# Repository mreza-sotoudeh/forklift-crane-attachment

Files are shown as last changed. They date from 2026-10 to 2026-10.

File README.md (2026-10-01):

# Forklift Crane Attachment

Design and analysis of an adjustable crane attachment for a forklift, including structural calculations, mechanical joints, manufacturing drawings, and a complete SolidWorks assembly.

## Authors

* Ali Sakhaei
* Mohammadreza Sotoudeh

## Project Overview

This academic machine-design project develops a removable crane attachment for a 3-ton forklift. The mechanism provides adjustable reach and boom angle while remaining fully demountable and manually adjustable.

The project covers forklift stability, static loading, structural members, bolts, pins, welds, component selection, CAD modeling, engineering drawings, and assembly documentation.

## Design Requirements

| Requirement | Value |
| --- | ---: |
| Forklift capacity | 3 tonnes |
| Fork length | 1000 mm |
| Fork cross-section | 120 × 40 mm |
| Fork spacing | 800 mm center-to-center |
| Maximum hook reach beyond fork tips | 2500 mm |
| Boom angles | 0°, 15°, 30°, and 45° |
| Hook-position increments | 200 mm |
| Required forklift stability factor of safety | 1.5 |
| Adjustment method | Manual |
| Installation | Fully removable |

## Key Design Features

* Telescopic boom for adjustable lifting reach
* Multiple predefined boom-angle positions
* Hook locations arranged at 200 mm intervals
* Removable connection to the forklift forks
* Bolted, pinned, and welded mechanical joints
* Structural calculations for the main load-carrying components
* Complete SolidWorks parts, assemblies, and engineering drawings

## Design and Analysis

The design process included:

* Forklift stability evaluation at different boom configurations
* Static load analysis of the boom and supporting structure
* Selection and verification of bolts and clevis pins
* Weld sizing and connection assessment
* Evaluation of rectangular hollow sections, plates, channels, and angles
* Preparation of a bill of materials and manufacturing drawings
* Assembly modeling and interference checking in SolidWorks

## CAD Model

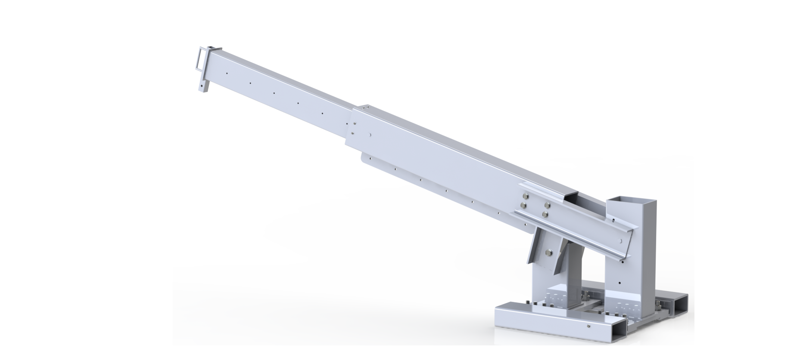
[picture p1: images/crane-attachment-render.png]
Crane attachment render


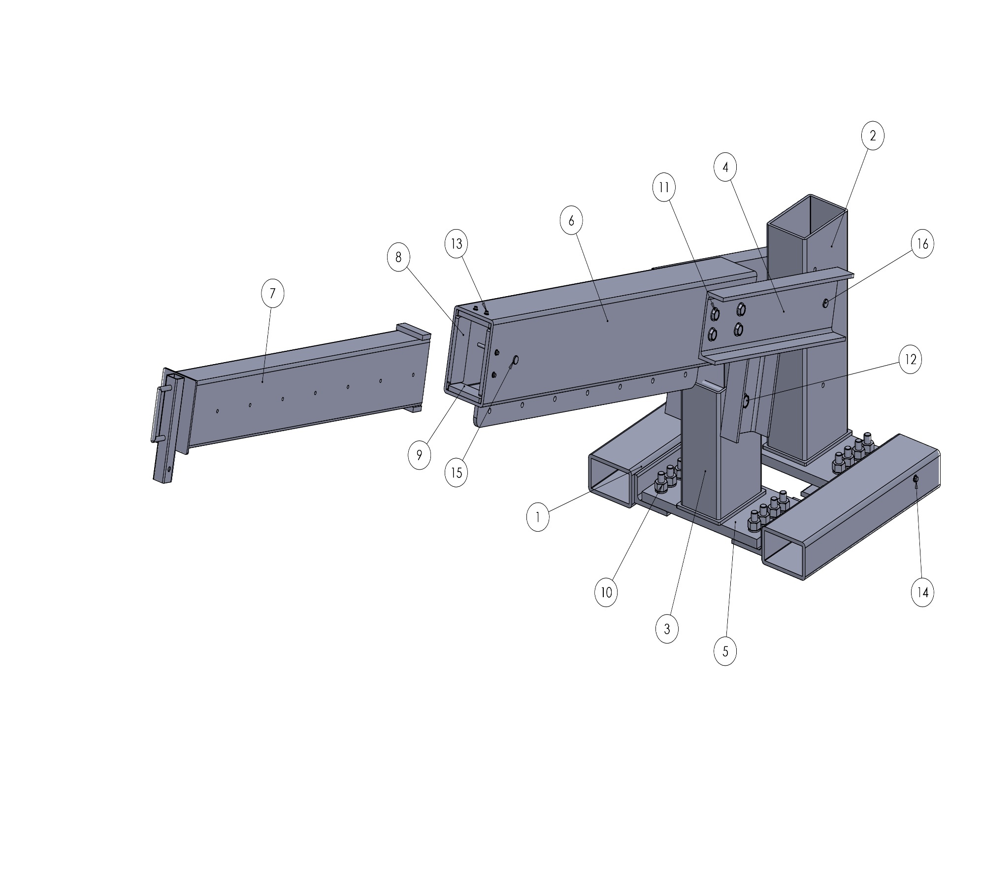
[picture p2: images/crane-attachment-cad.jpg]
Crane attachment CAD model


### Installation Context

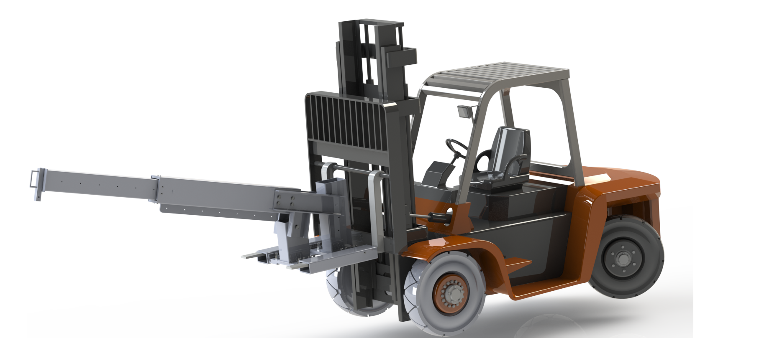
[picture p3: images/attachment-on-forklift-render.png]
Crane attachment installed on forklift


The forklift vehicle shown above is a pre-existing reference model used only to demonstrate the installation context. It is not included in this repository and is not presented as original work.

## Main Structural Components

| Component | Specification |
| --- | --- |
| Outer boom | 260 × 180 × 10 mm rectangular hollow section |
| Inner extension | 200 × 120 × 8 mm rectangular hollow section |
| Base profile | 200 × 120 × 12.5 mm rectangular hollow section |
| Support channel | UAP 200, 2100 mm long |
| Main high-strength plate | StE500, 570 × 530 × 30 mm |
| General plates | St37 steel |
| Structural angle | L 150 × 90 × 15 mm |
| Main fasteners | M24 and M20 grade 8.8 bolts |
| Lifting hardware | Grade 80 hook and shackle |

## Repository Contents

```text
.
├── docs/
│   └── forklift-crane-attachment-report-en.pdf
├── images/
│   ├── attachment-on-forklift-render.png
│   ├── crane-attachment-cad.jpg
│   └── crane-attachment-render.png
├── solidworks/
│   ├── parts and subassemblies
│   ├── main assembly
│   └── engineering drawings
└── README.md
```

## Project Report

[View the English project report](docs/forklift-crane-attachment-report-en.pdf)

## Software

* SolidWorks
* Microsoft Excel
* Engineering calculation and documentation tools

## Limitations and Safety

This repository presents an academic design. The attachment has not been fabricated, proof-load tested, certified, or approved for lifting operations.

Any real-world implementation would require verified material certificates, code-based lifting-device calculations, fatigue and buckling checks, qualified welding procedures, physical testing, inspection requirements, manufacturer approval, and review by a qualified engineer.

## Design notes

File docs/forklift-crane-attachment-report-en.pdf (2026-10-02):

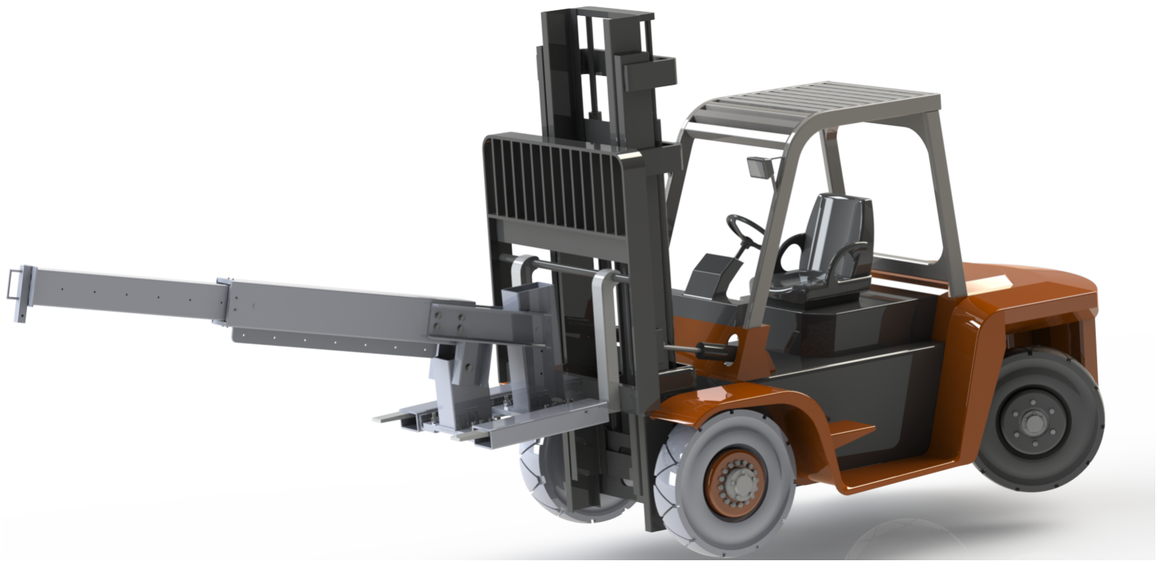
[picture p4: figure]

Ali Sakhaei and Mohammadreza Sotude | Page 1

# Forklift Crane Attachment

### Design and Analysis of an Adjustable, Demountable Lifting Boom

The crane attachment shown in operating context. The forklift vehicle is a reference model; the attachment is the project scope.

COURSE | Machine Design I
DESIGN | Adjustable crane attachment for a 3-ton forklift
AUTHORS | Ali Sakhaei and Mohammadreza Sotude
TOOLS | SolidWorks, analytical strength calculations, cost estimation

FORKLIFT CRANE ATTACHMENT

# 1. Design Problem and Requirements

The objective was to design a crane boom that mounts on the forks of a 3-ton forklift and extends its ability to lift loads that cannot be reached directly. The attachment had to remain manually adjustable, mechanically simple, transportable, and fully demountable.

### Functional requirements

Requirement | Specified value or condition
Host vehicle | 3-ton forklift
Fork geometry | 1,000 mm long, 120 mm wide, 40 mm thick
Fork spacing | 800 mm center-to-center during installation
Maximum hook reach | 2,500 mm beyond the fork tips
Boom angle | 0°, 15°, 30°, and 45°
Hook-position increments | 200 mm along the adjustable extension
Stability criterion | Forklift stability evaluated with a factor of safety of 1.5
Assembly | Detachable components that can be transported and assembled on site

### Design scope

- Conceptual design of the base frame, boom, telescoping extension, hook, pins, and fork connections.
- Static calculations for the forklift stability limit and critical load cases.
- Sizing of bolts, pins, welded joints, structural tubes, channels, angles, and plates.
- SolidWorks part and assembly models with manufacturing and assembly drawings.
- Bill of materials, assembly procedure, product sheet, and approximate fabrication cost.

The project concerns the crane attachment. A pre-existing forklift CAD model was used only to show the installation context and is not included among the published design files.

# 2. Load Cases and Structural Analysis

The allowable lifted load changes with hook reach and boom angle. The design therefore considers multiple boom positions rather than a single rated load. Forklift stability provides the first limit, followed by stress and joint checks for the attachment itself.

### Stability and member checks

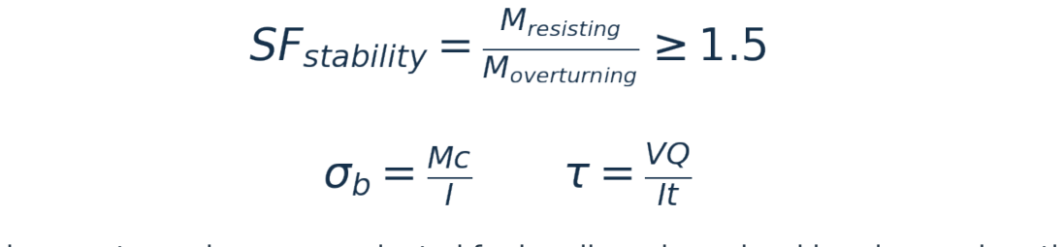
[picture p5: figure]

The boom and support members are evaluated for bending, shear, local bearing, and section strength. The telescoping arrangement requires checks at both maximum extension and the discrete pin locations because these positions change the bending moment and the contact forces.

### Connection checks

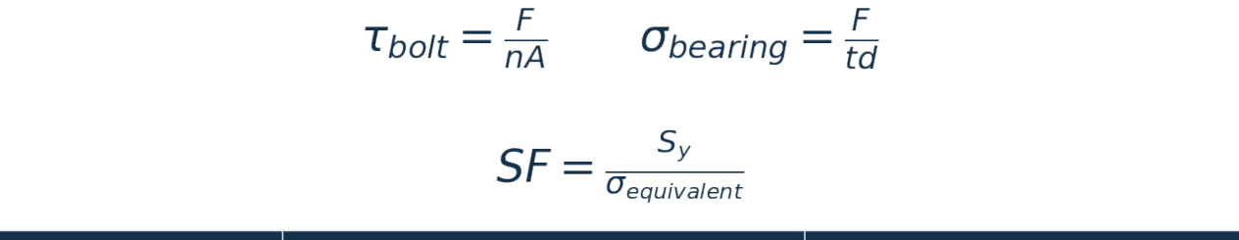
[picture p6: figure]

Connection | Elements evaluated | Primary failure modes
Fork-mounted base | M24 and M20 bolts, plates, channels | Bolt shear, bearing, plate bending
Boom pivot | M16 clevis pin and supporting plates | Double shear, bearing, bending
Extension lock | M10 clevis pin and liners | Pin shear, local bearing, tube deformation
Hook connection | Grade 80 hook and shackle | Rated capacity and pin loading
Welded subassemblies | Multiple fillet-weld sizes | Throat shear and combined loading

The calculations are retained in the original academic report. This portfolio edition summarizes the design logic and does not replace a certified lifting-device calculation or inspection.

# 3. Structural Components and Materials

The structure combines hollow sections, channels, angles, and plates. Standard fasteners and removable pins allow the attachment to be assembled, adjusted, and disassembled without permanent connection to the forklift.

Component | Section or material | Function
Outer boom | 260 × 180 × 10 mm rectangular hollow section | Primary bending member
Inner extension | 200 × 120 × 8 mm rectangular hollow section | Adjustable hook reach
Base profile | 200 × 120 × 12.5 mm rectangular hollow section | Transfers loads to fork-mounted frame
Channel | UAP 200, 2,100 mm long | Base-frame load distribution
High-strength plate | StE500, 570 × 530 × 30 mm | Critical connection region
General plates | St37, several thicknesses | Brackets, liners, and support plates
Angle | L 150 × 90 × 15 mm | Fork-frame support

### Selected standard hardware

- Twenty-four M24 bolts for the main bolted structure, including specified strength classes.
- Eight M20 grade 8.8 bolts and eight M8 flange screws.
- M16 and M10 clevis pins with spring cotters.
- Grade 80 hook and screw-pin shackle.
- Fillet welds with several specified throat sizes for the welded subassemblies.


SolidWorks model of the crane attachment without the third-party forklift model.

# 4. CAD Model and Manufacturing Documentation

The SolidWorks model is divided into a fork-mounted base, pivoting boom, telescoping inner tube, liners, pins, plates, and connection hardware. Separate assembly and part files support editing and drawing generation.

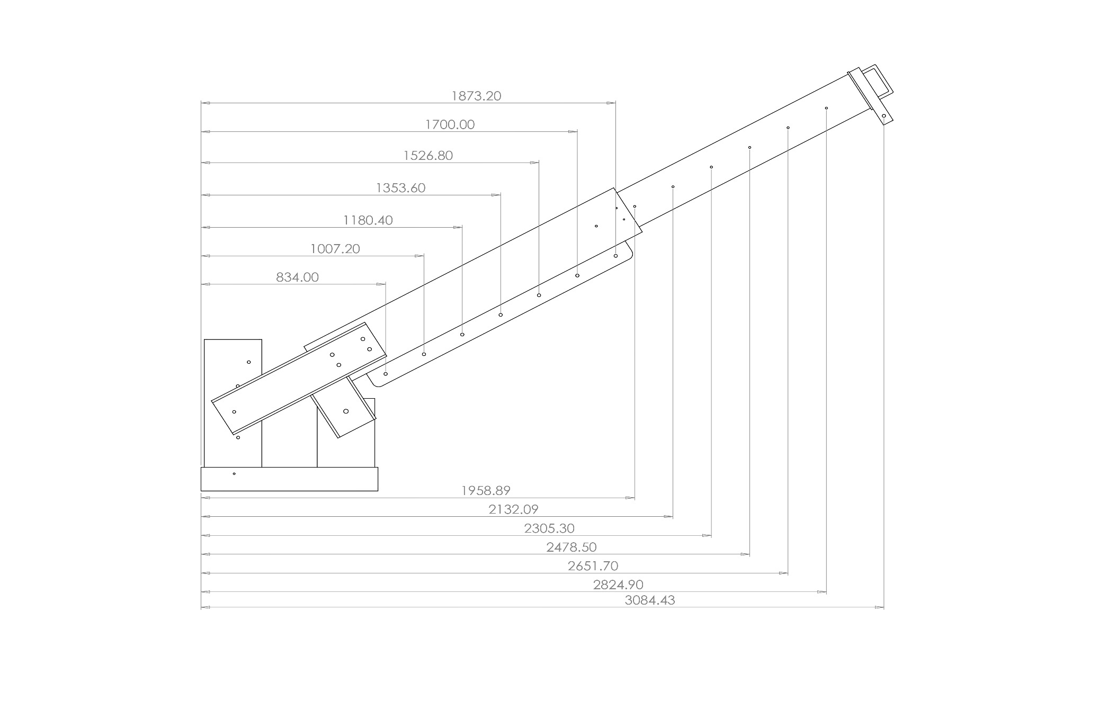
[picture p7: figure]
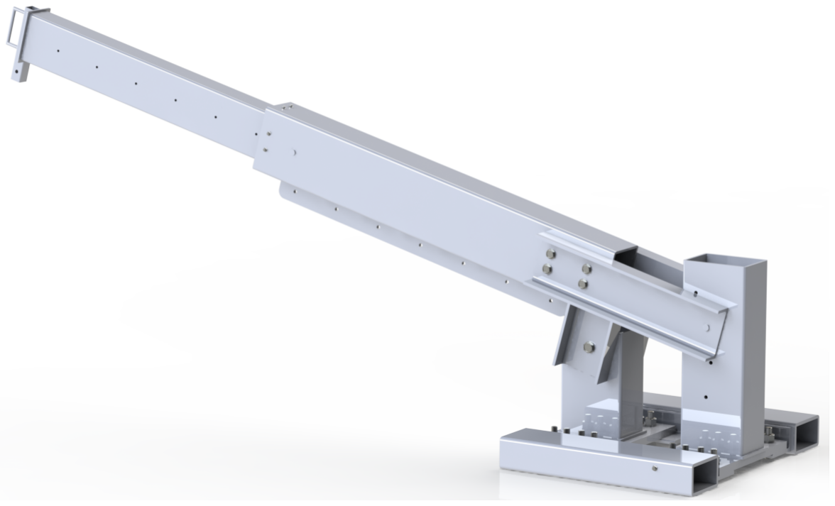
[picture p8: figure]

Rendered attachment | Boom-position drawing

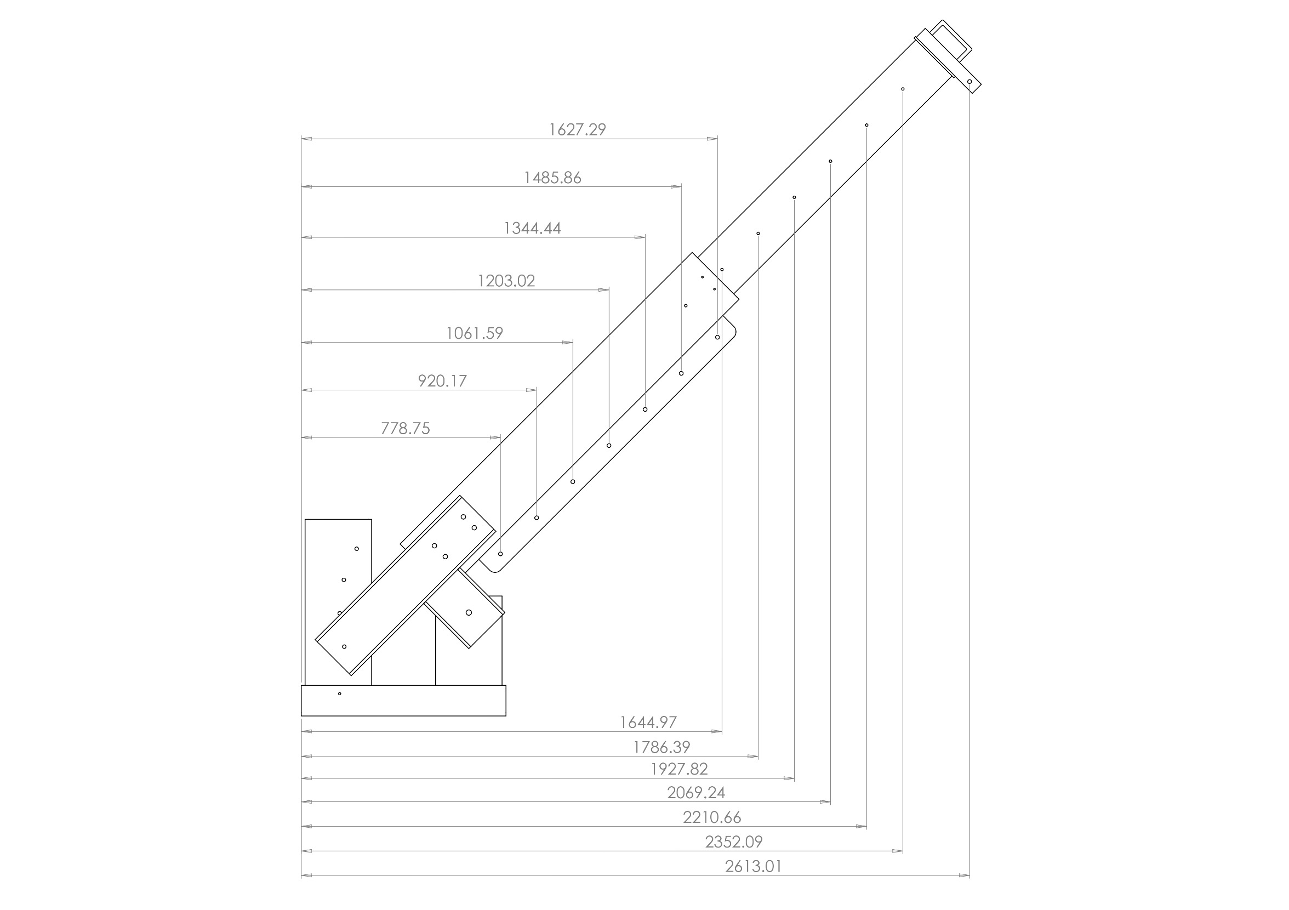
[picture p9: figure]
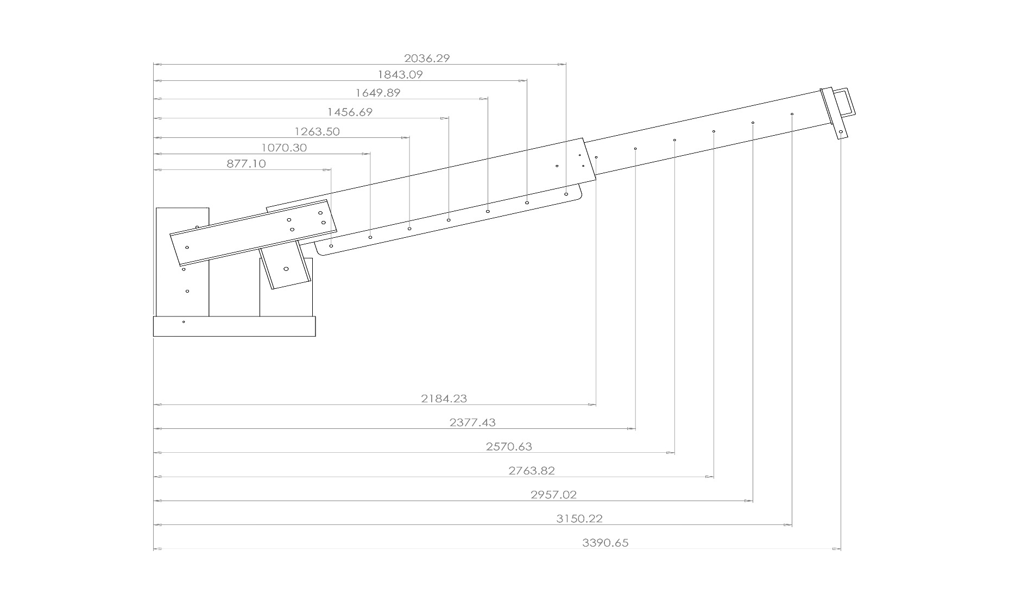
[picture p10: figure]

Adjustment configuration | Extended and inclined configuration

### Drawing package

The published files include SolidWorks parts and assemblies, native drawing files, and PDF exports for the main base and boom assemblies. Drawings cover the primary components, assembly relationships, discrete boom angles, and mass configurations.

The original folder relationships are preserved to reduce broken references when the assemblies are opened. The unrelated forklift reference assembly and its component files are excluded.

# 5. Assembly Strategy and Cost Estimate

The design separates the product into transportable subassemblies. The base frame is positioned over the forklift forks and secured through bolted connections. The outer boom is attached to the base through the main pivot. The telescoping member is inserted into the boom and locked at a selected reach with a removable pin.

### Assembly sequence

1 | Prepare the welded base-frame and boom subassemblies from the specified profiles and plates.
2 | Position the base profiles over the two forklift forks and install the structural fasteners.
3 | Connect the outer boom to the base using the pivot pin and cotter.
4 | Insert the telescoping extension, liners, handle, and locking plates.
5 | Select the required extension and boom angle, then secure the corresponding pins and fasteners.
6 | Install the shackle and rated hook and perform a pre-use joint and alignment inspection.

### Cost estimate

Item | Approximate value | Basis
Steel sections, plates, and hardware | 26.82 million toman | Reported market prices in late May and early June 2025
Welding | 0.34 million toman | Estimated weld lengths and size-dependent rates
Epoxy coating consumed | 0.83 million toman | About 2.64 kg for a 100 μm dry film over 12 m²
Rounded fabricated structure | Approximately 28 million toman | Academic estimate; excludes time-dependent purchasing variation

Prices are historical and location-dependent. They are included to demonstrate design-for-manufacture and cost awareness, not to provide a current quotation.

# 6. Conclusions and Repository Scope

The project develops a complete mechanical attachment from requirements to a manufacturable CAD package. Its strongest aspect is the combination of stability assessment, component and joint calculations, adjustable geometry, assembly planning, drawings, and cost estimation.

### Main outcomes

- A demountable crane attachment compatible with the specified forklift fork geometry.
- Manual adjustment of hook reach up to 2.5 m and boom angle through four discrete positions.
- Analytical checks for structural members, bolts, pins, bearing regions, and welds.
- A detailed SolidWorks model with manufacturing and assembly drawings.
- A bill of materials, assembly sequence, and approximate fabrication cost.

### Repository contents

Folder | Contents
solidworks/ | Original attachment parts, assemblies, drawings, and PDF drawing exports
images/ | Clean project renders and selected configuration drawings
docs/ | English portfolio report

### Limitations and safety

This is an academic design and has not been fabricated, proof-load tested, certified, or approved for lifting operations. A real implementation would require verified material certificates, code-based lifting-device calculations, weld-procedure qualification, fatigue and buckling checks, forklift-manufacturer approval, physical testing, inspection requirements, and review by a qualified engineer.

### Authorship and external assets

The crane attachment was developed jointly by Ali Sakhaei and Mohammadreza Sotude. The vehicle model used in contextual renders was a pre-existing reference asset and is not included in the repository or presented as original work.

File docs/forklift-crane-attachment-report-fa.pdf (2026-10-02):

دانشگاه صنعتي شريف
دانشكده مهندسي مكانیک

گزارش درس طراحي اجز اء ماشین 1

عنوان

## پروژه طراحي دکل جرثقیل روی لیفتراک

نگارش

### علي سخايي محمدرضا ستوده

دکتر دورعلي

خرداد 1404

چكیده أ

### طراحي دکل جرثقیل قابل نصب روی لیفتراک

چكیده

در اين پروژه، به طراحي و تحلیل دکل جرثقیل نصببشبونده بر روی لیفتراک پرداخته شبده اسبهد دز ا اين طرح، افزايش قابلیه جابهجايي و باربرداری لیفتراک در محیط ای صببنعتي و کارگا ي، بدون نیا به خريد جرثقیل ای مجزا ميباشبدد مننین سبا وکار اتصباک دکل به شباسبي لیفتراک بررسبي گرديده اسبهد نتايج حاصبل ا تحلیل ا نشبان ميد د که دکل طراحيشبده ضبمن دارا بودن اسبتحكان مناسبب، قابلیه کاربرد در محیط ای متنوع صبنعتي را دارا ميباشبدد اين طراحي ميتواند بهعنوان يک را كار اقتصبادی و انعطازپذير برای افزايش بهرهوری لیفتراک ای موجود مطرح گرددد

فهرسه مطالب ب

صفحه | فهرسه مطالب

1 مقدمه دددددددددددددددددددددددددددددددددددددددددددددددددددددددددددددددددددددددددددددددددددددددددددددددددددددددددددددددددددددددددددددددددددددددددددددددددددددددددددددددد 1 2 تشر ي ح مسئلهدددددددددددددددددددددددددددددددددددددددددددددددددددددددددددددددددددددددددددددددددددددددددددددددددددددددددددددددددددددددددددددددددددددددددددددددددددد 2 3 محاسبات استات ی ك ي اول ی ه دددددددددددددددددددددددددددددددددددددددددددددددددددددددددددددددددددددددددددددددددددددددددددددددددددددددددددددددددددددددددددددددد 3 4 محاسبات پ ی چ و پ ی ن دددددددددددددددددددددددددددددددددددددددددددددددددددددددددددددددددددددددددددددددددددددددددددددددددددددددددددددددددددددددددددددددددددددد 4
4 | دددددددددددددددددددددددددددددددددددددددددددددددددددددددددددددددددددددددددددددددددددددددددددددددددددددددددددددددددددددددددددددددددددددددددددددددددددددددددددد | T-Screws 4.1
4.2 پیچ Bددددددددددددددددددددددددددددددددددددددددددددددددددددددددددددددددددددددددددددددددددددددددددددددددددددددددددددددددددددددددددددددددددددددددددددددددددددددددددددددددددددد5
4.3 پین Aددددددددددددددددددددددددددددددددددددددددددددددددددددددددددددددددددددددددددددددددددددددددددددددددددددددددددددددددددددددددددددددددددددددددددددددددددددددددددددددددددددد5
4.4 پین C( بین دکل و پروف یل داخلي( دددددددددددددددددددددددددددددددددددددددددددددددددددددددددددددددددددددددددددددددددددددددددددددددددددددددددددددددددد6 4.5 پین متصل به قالب ددددددددددددددددددددددددددددددددددددددددددددددددددددددددددددددددددددددددددددددددددددددددددددددددددددددددددددددددددددددددددددددددددددددددددددددد6 4.6 پیچ ا ی ناوداني دددددددددددددددددددددددددددددددددددددددددددددددددددددددددددددددددددددددددددددددددددددددددددددددددددددددددددددددددددددددددددددددددددددددددددددددددددددد7 4.7 پیچ ا ی نبش ي )قسمه جلويي شاخک( ددددددددددددددددددددددددددددددددددددددددددددددددددددددددددددددددددددددددددددددددددددددددددددددددددددددددددددد8 4.8 پیچ ا ی نبش ي )قسمه ابتدايي شاخک( دددددددددددددددددددددددددددددددددددددددددددددددددددددددددددددددددددددددددددددددددددددددددددددددددددددددددددد9 4.9 پیچ ا ی بین دو ورق دددددددددددددددددددددددددددددددددددددددددددددددددددددددددددددددددددددددددددددددددددددددددددددددددددددددددددددددددددددددددددددددددددددددددد10 4.10پیچ ای بین دکل و چهار عدد ورق دددددددددددددددددددددددددددددددددددددددددددددددددددددددددددددددددددددددددددددددددددددددددددددددددددددددددددددددد11
5 محاسبات جوش دددددددددددددددددددددددددددددددددددددددددددددددددددددددددددددددددددددددددددددددددددددددددددددددددددددددددددددددددددددددددددددددددددددددددددد 12 5.1 جوش دو عدد ناوداني دددددددددددددددددددددددددددددددددددددددددددددددددددددددددددددددددددددددددددددددددددددددددددددددددددددددددددددددددددددددددددددددددددددددد12 5.2 ير دکل ددددددددددددددددددددددددددددددددددددددددددددددددددددددددددددددددددددددددددددددددددددددددددددددددددددددددددددددددددددددددددددددددددددددددددددددددددددددددددددددد13
5.3 جوش نبشي به پروف یل روی شاخکدددددددددددددددددددددددددددددددددددددددددددددددددددددددددددددددددددددددددددددددددددددددددددددددددددددددددددددددد14 5.4 جوش ورق ير پروف یل ای جلو و عقب ددددددددددددددددددددددددددددددددددددددددددددددددددددددددددددددددددددددددددددددددددددددددددددددددددددددددددد15 5.5 جوش بین پروف یل مربعي و ورق در انتها دددددددددددددددددددددددددددددددددددددددددددددددددددددددددددددددددددددددددددددددددددددددددددددددددددددددد16 5.6 جوش بین ورق آخر پروفیل داخل دکل دددددددددددددددددددددددددددددددددددددددددددددددددددددددددددددددددددددددددددددددددددددددددددددددددددددددددد17 5.7 جوش دسته ددددددددددددددددددددددددددددددددددددددددددددددددددددددددددددددددددددددددددددددددددددددددددددددددددددددددددددددددددددددددددددددددددددددددددددددددددددددددد18
6 محاسبات مقاومه اجزا ء ددددددددددددددددددددددددددددددددددددددددددددددددددددددددددددددددددددددددددددددددددددددددددددددددددددددددددددددددددددددددددددددد 19 6.1 پروف یل داخل دکل دددددددددددددددددددددددددددددددددددددددددددددددددددددددددددددددددددددددددددددددددددددددددددددددددددددددددددددددددددددددددددددددددددددددددددددد19
6.2 دکل دددددددددددددددددددددددددددددددددددددددددددددددددددددددددددددددددددددددددددددددددددددددددددددددددددددددددددددددددددددددددددددددددددددددددددددددددددددددددددددددددددد19
6.3 ناودانيدددددددددددددددددددددددددددددددددددددددددددددددددددددددددددددددددددددددددددددددددددددددددددددددددددددددددددددددددددددددددددددددددددددددددددددددددددددددددددددددددد20
6.4 ورق جلويي )روی نبشي ا( ددددددددددددددددددددددددددددددددددددددددددددددددددددددددددددددددددددددددددددددددددددددددددددددددددددددددددددددددددددددددددددددد21 6.5 ورق پشتي )روی نبش ي ا ( دددددددددددددددددددددددددددددددددددددددددددددددددددددددددددددددددددددددددددددددددددددددددددددددددددددددددددددددددددددددددددددددد22 6.6 ستون ای متصل به پ ین A و پیچ Bددددددددددددددددددددددددددددددددددددددددددددددددددددددددددددددددددددددددددددددددددددددددددددددددددددددددددددد23 6.7 باق ي اجزاءدددددددددددددددددددددددددددددددددددددددددددددددددددددددددددددددددددددددددددددددددددددددددددددددددددددددددددددددددددددددددددددددددددددددددددددددددددددددددددد23

فهرسه مطالب ب

7 ل ی سه مواد و قطعاتددددددددددددددددددددددددددددددددددددددددددددددددددددددددددددددددددددددددددددددددددددددددددددددددددددددددددددددددددددددددددددددددددددد 24 8 نقشه ا دددددددددددددددددددددددددددددددددددددددددددددددددددددددددددددددددددددددددددددددددددددددددددددددددددددددددددددددددددددددددددددددددددددددددددددددددددددددددددد 27 8.1 دکل دددددددددددددددددددددددددددددددددددددددددددددددددددددددددددددددددددددددددددددددددددددددددددددددددددددددددددددددددددددددددددددددددددددددددددددددددددددددددددددددددددد27
8.2 پروف یل داخل دکل دددددددددددددددددددددددددددددددددددددددددددددددددددددددددددددددددددددددددددددددددددددددددددددددددددددددددددددددددددددددددددددددددددددددددددددد28
8.3 قاب دددددددددددددددددددددددددددددددددددددددددددددددددددددددددددددددددددددددددددددددددددددددددددددددددددددددددددددددددددددددددددددددددددددددددددددددددددددددددددددددددددد29
8.4 حاله ای قرارگ یری سا هددددددددددددددددددددددددددددددددددددددددددددددددددددددددددددددددددددددددددددددددددددددددددددددددددددددددددددددددددددددددددددددددد31
9 کاتالوگ محصوک ددددددددددددددددددددددددددددددددددددددددددددددددددددددددددددددددددددددددددددددددددددددددددددددددددددددددددددددددددددددددددددددددددددددددددد 34 10 روش مونتاژ دددددددددددددددددددددددددددددددددددددددددددددددددددددددددددددددددددددددددددددددددددددددددددددددددددددددددددددددددددددددددددددددددددددددددددددددددددد 36 11 برآورد ق ی مه قطعات سا ه جرثق ی ل )نرخ رو با ار ا ي ران ( دددددددددددددددددددددددددددددددددددددددددددددددددددددددددددددددددددددددد 38 11.1ق یمه رو قطعات فوالد ی ددددددددددددددددددددددددددددددددددددددددددددددددددددددددددددددددددددددددددددددددددددددددددددددددددددددددددددددددددددددددددددددددد38 11.2 زينه جوشكاری سا ه ددددددددددددددددددددددددددددددددددددددددددددددددددددددددددددددددددددددددددددددددددددددددددددددددددددددددددددددددددددددددددددددددددددددد41 11.3محاسبه مقدار و زينه رنگ مورد نیا ددددددددددددددددددددددددددددددددددددددددددددددددددددددددددددددددددددددددددددددددددددددددددددددددددددددددددددد42 11.4جمعبندی: ق یمه تمانشده نهايي سا ه ددددددددددددددددددددددددددددددددددددددددددددددددددددددددددددددددددددددددددددددددددددددددددددددددددددددددددد42
12 رندرگ ی ر ی ا ددددددددددددددددددددددددددددددددددددددددددددددددددددددددددددددددددددددددددددددددددددددددددددددددددددددددددددددددددددددددددددددددددددددددددددددددددد 44 13 پ ی وسهدددددددددددددددددددددددددددددددددددددددددددددددددددددددددددددددددددددددددددددددددددددددددددددددددددددددددددددددددددددددددددددددددددددددددددددددددددددددددددد 46

فهرسه اشكاک د

فهرسه اشكاک صفحه

شكل 12.1 جرتق ی ل )مجزا ا ل ی فتراک( ددددددددددددددددددددددددددددددددددددددددددددددددددددددددددددددددددددددددددددددددددددددددددددددددددددددددددددددددددددددددددد44 شكل 12.2 لی فتراک و دکل متصل به آن ددددددددددددددددددددددددددددددددددددددددددددددددددددددددددددددددددددددددددددددددددددددددددددددددددددددددددددددددددددددد45

فهرسه جداوک ه

فهرسه جداوک صفحه

جدوک 7-1 ل یسه قطعات ددددددددددددددددددددددددددددددددددددددددددددددددددددددددددددددددددددددددددددددددددددددددددددددددددددددددددددددددددددددددددددددددددددددددددددددددد26 جدوک 9-1 List Partددددددددددددددددددددددددددددددددددددددددددددددددددددددددددددددددددددددددددددددددددددددددددددددددددددددددددددددددددددددددددددددددددددددددددددددددددددد35 جدوک 11-1 قی مه قطعات دددددددددددددددددددددددددددددددددددددددددددددددددددددددددددددددددددددددددددددددددددددددددددددددددددددددددددددددددددددددددددددددددددددددددددددد41

فصل اوک: مقدمه 1

## 1 مقدمه

لیفتراک با ببه عنوان يكي ا پرکباربردترين تجهیزات جبابجبايي در صبببنبايع، انببار با و کبارگباه بای صبببنعتي شبناخته ميشبوندد با وجود کارايي باال، محدوديه ايي در کاربرد آن ا وجود دارد؛ بهويژه نگان مواجهه با بار ايي که در فواصبل دورتر ا نوک شباخک ا قرار دارند يا در ارتفاعي متفاوت ا سبطح قابل دسبترسبي لیفتراک واقع شبدهاندد در چنین شبرايطي، اسبتفاده ا تجهیزات جانبي مانند دکل ای افزايشبي ميتواند را كاری عملي و مقرونبهصرفه برای افزايش دامنه عملكرد لیفتراک ا باشد . در اين پروژه، طراحي يک دکل جرثقیل قابل نصببب بر روی شبباخک ای لیفتراک ۳ تني مورد بررسبي قرار گرفته اسبهد اين دکل بايد عالوه بر سبا گاری کامل با ابعاد و مشبخصبات فني شباخک ای لیفتراک، توانبايي تنیی طوک تبا حبداک ر ۵د۲ متر ا نوک شببباخبک با، تنیی اويبه تبا ۴۵ درجبه در چهبار موقعیه، و مننین تحمل بار متناسبب با پايداری لیفتراک را داشبته باشبدد ا سبوی ديگر، سبا ه دکل بايد به گونهای طراحي شبود که قابلیه مونتاژ و دمونتاژ کامل را داشبته و تمامي قطعات آن در يک بسبتهبندی قابل حمل جای بگیرند .
اين طرح با رويكردی مهندسببي، با تمرکز بر جنبه ای ايمني، پايداری، سببادگي عملكرد و سببهوله حملونقل ارائه شبده اسبهد در ادامه، مراحل مختلف طراحي مفهومي، مدکسبا ی سبهبعدی، تحلیل ای اسبتاتیكي، تهیه نقشبه ای اجرايي، لیسبه قطعات و برآورد زينه محصبوک تشبريح گرديده اسبهد امید اسبه اين محصوک بتواند به عنوان يک راهحل کاربردی در صنايع مختلف مورد استفاده قرار گیرد

فصل دون: تشريح مسئله 2

## 2 تشريح مسئله

برای بلند کردن بار ای غیر قابل دسببترسببي توسببط لیفه تراک میخوا ی يک دکل قابل نصببب روی شاخک ای لیفه تراک با مشخصات ير طراحي کنی د لیفه تراک 3 تن اسبه و طوک شباخک ا 1 متر و تا عرض جلوی لیفتراک قابل اسبتقرار سبتندد
عرض شباخک ا 120 ن ن و ضبخامه آنها 40 ن ند تعادک لیفه تراک با ضبريب اطمینان 1.5 روی مرکز فاصله شاخكها و مرکز طولي آنها قرارداردد مشبتری درخواسبه يک دکل با حداک ر فاصبله قالب 2.5 متر ا نوک شباخک ا و تقريبا مسبطح با
ير شباخک ا در حاله افقي دکل را دارد که بتواند بار متناسبب با تعادک لیفتراک را در فواصبل مختلف تحمل نمايدد ضبمنا درخواسبه دارد که بتواند دکل را تا اويه 45 درجه به سبمه باال اويه بد د )در 4 پله( و نیز بتواند ا نوک شبباخكها تا انتهای 2.5 متری در فواصببل 200 ن ن قالب را نصببب کندد فاصببله شباخک ا وقتي پايه دکل روی آن نصبب ميشبود 800 ن ن )مرکز تا مرکز شباخک ا(د تغییر اويه دکل و افزايش طوک آن با دسبه انجان ميشبود و بايد مكانیزن ای سباده و مقاون برای آن در نیر گرفهد کارفرما يک درخواسبه ديگر دارد و آن اينكه اين محصببوک نهايتا بصبورت يک محصببوک قابل مونتاژ طراحي گرددد يعني اينكه قطعات بتوانند با پیچ به متصبل شبوند و دکل و پايه ای آن و سبا ه نصبب شبونده روی شباخكها مه ا قابل جداسبا ی باشبند و بتوان آن ا را در جعبهای که به عرض مناسبب دکل باشبد جا داد و در محل آنرا مونتاژ کردد

طرح مناسبب را برای برآوری خواسبه اين مشبتری تهیه نموده و محاسببات مربوطه را انجان د یدد نقشبه ای اجرايي سباخه قطعات، نقشبه مونتاژی، شبكل محصبوک تمان شبدهد شبكل محصبوک نصبب شبده روی شاخكها، لیسه مواد ال ن و قیمه تمان شده، و کاتالوگ محصوک خودرا در گزارش ارائه د ید .

فصل سون: محاسبات استاتیكي اولیه 3

## 3 محاسبات استاتیكي اولیه

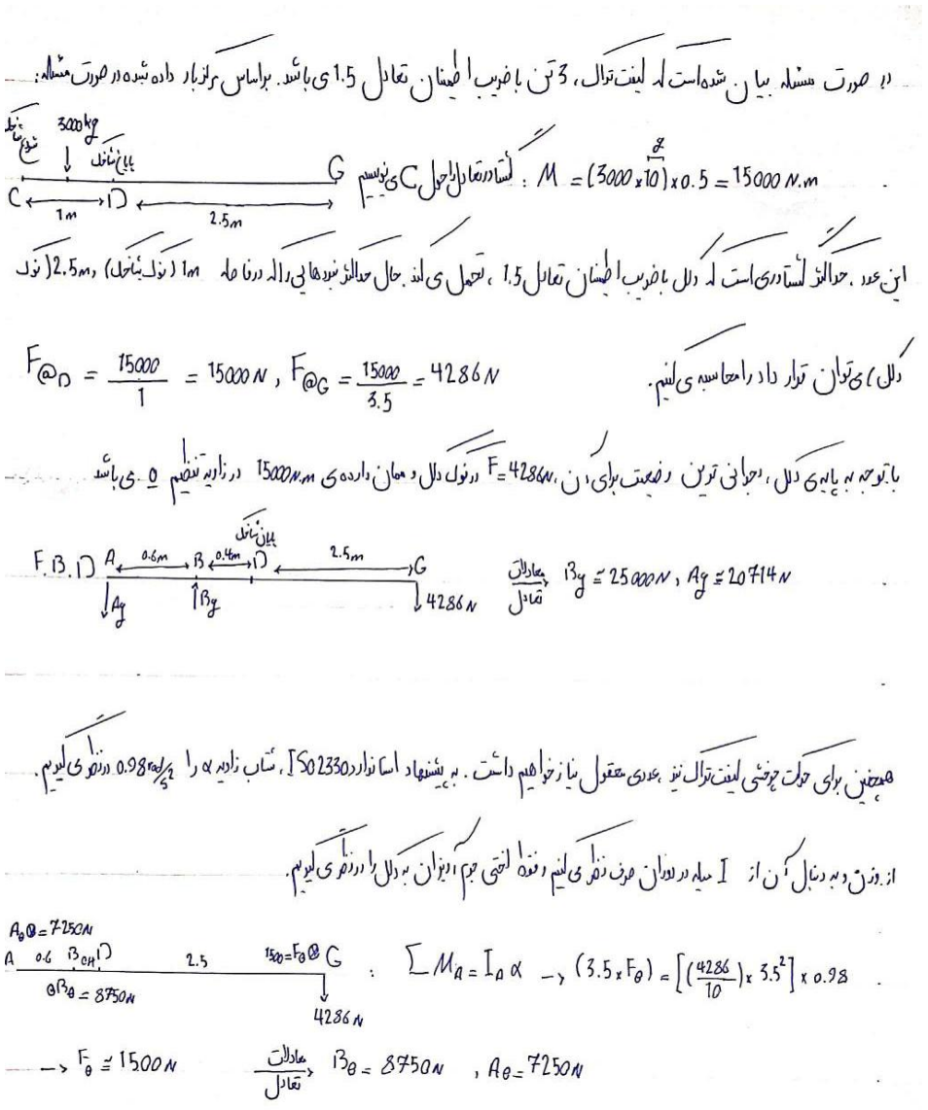
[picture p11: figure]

## 4 محاسبات پیچ و پین

فصل چهارن: محاسبات پیچ و پین 4

T-Screws 4.1

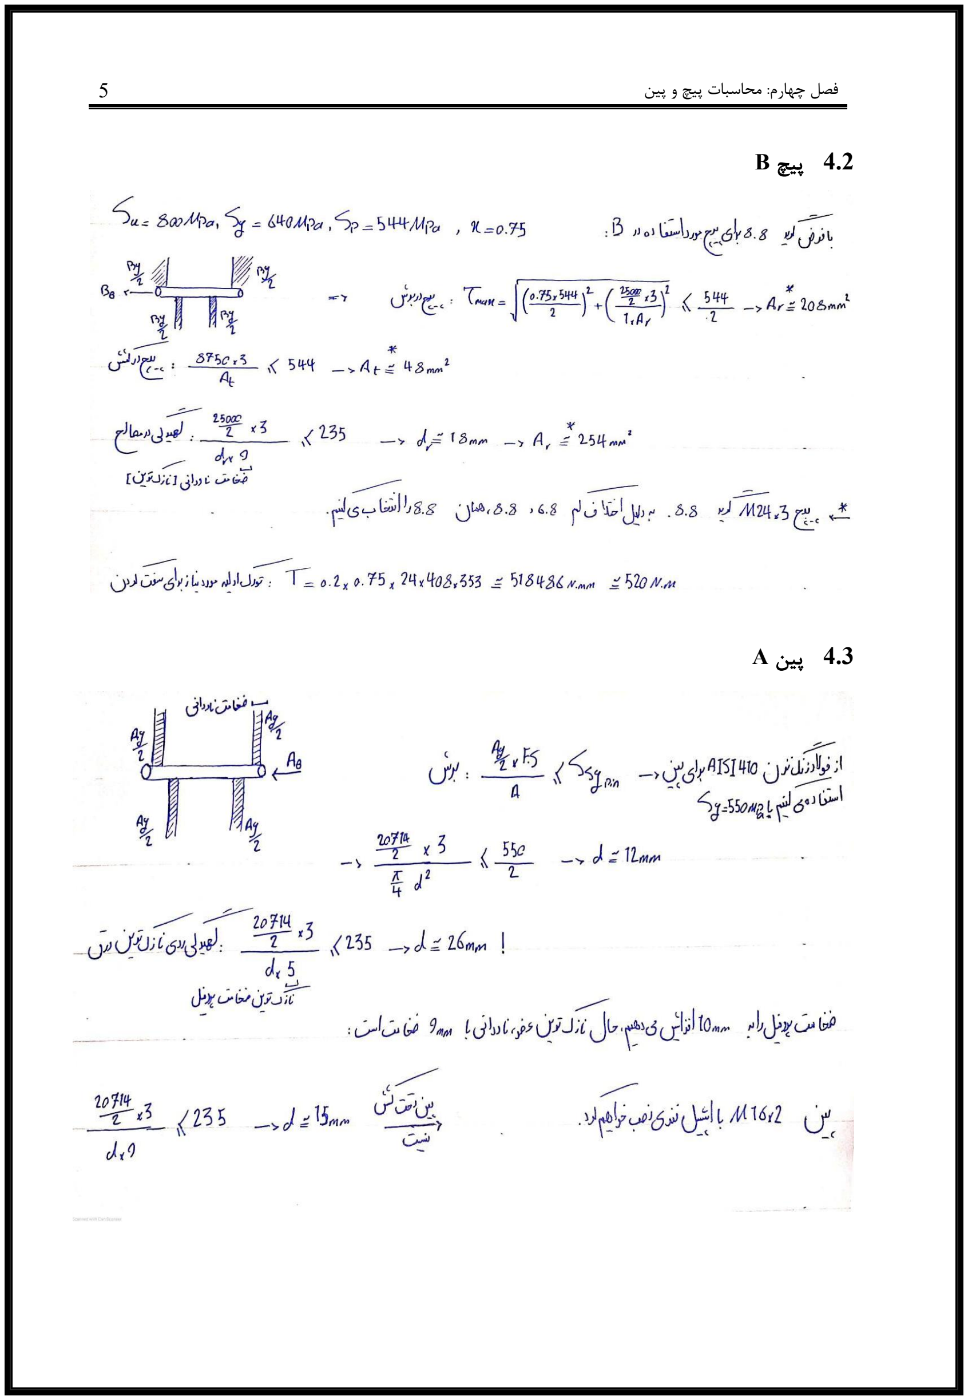
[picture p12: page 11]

فصل چهارن: محاسبات پیچ و پین 5

### 4.2 پیچ B

### 4.3 پین A

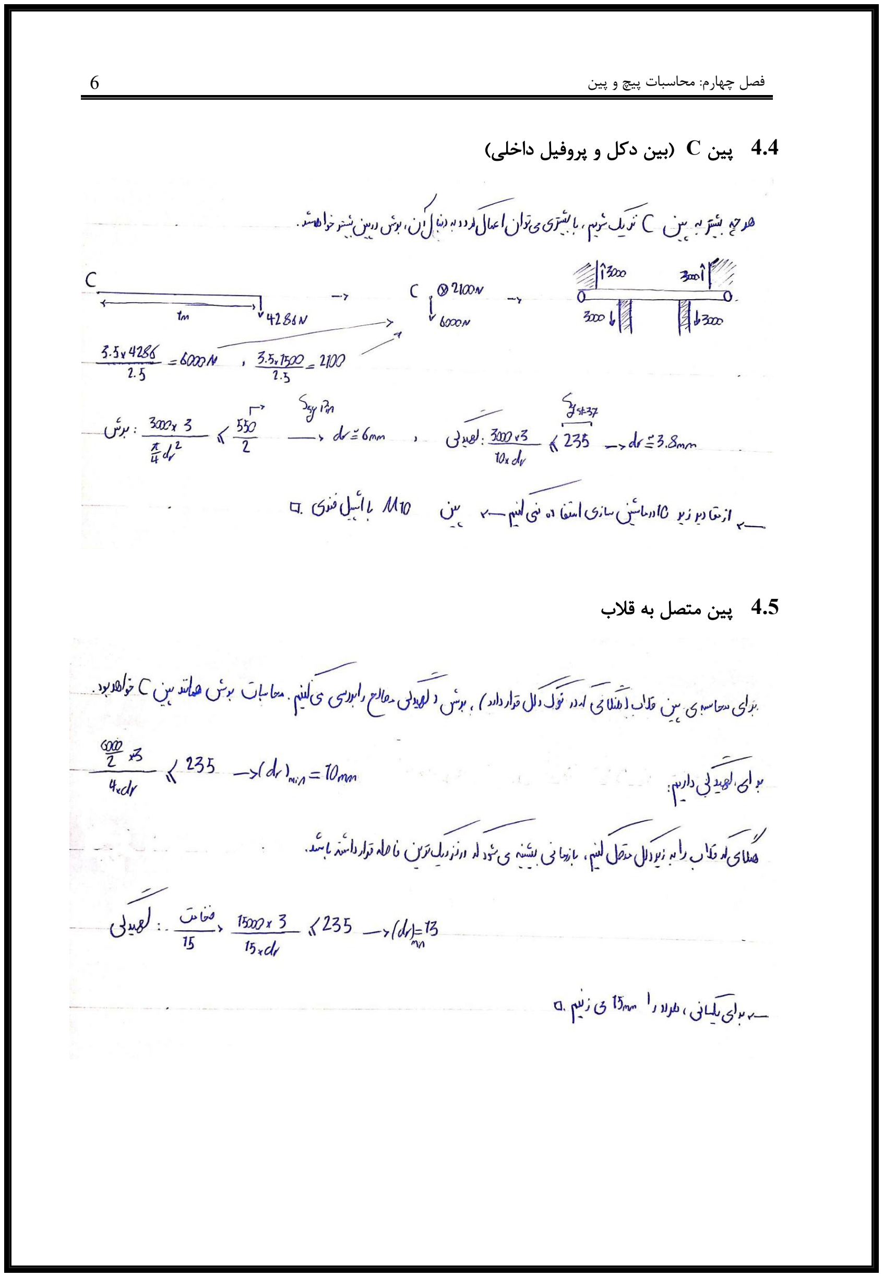
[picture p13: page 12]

فصل چهارن: محاسبات پیچ و پین 6

### 4.4 پین C( بین دکل و پروفیل داخلي(

### 4.5 پین متصل به قالب

4. پیچ ای ناوداني | فصل چهارن: محاسبات پیچ و پین 7

6

فصل چهارن: محاسبات پیچ و پین 8

### 4.7 پیچ ای نبشي )قسمه جلويي شاخک(

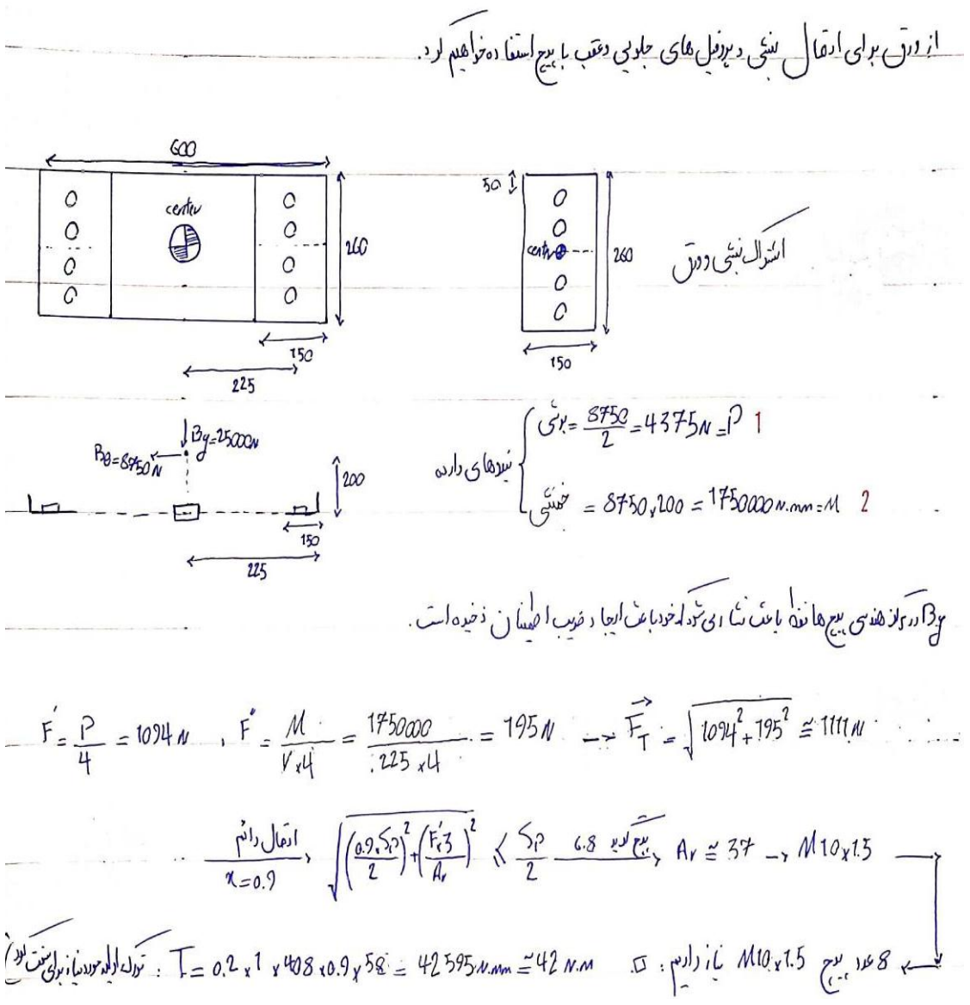
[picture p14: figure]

ال ن به ذکر اسبه با اين که پیچ ای 1.5×10M برای اين قسبمه محاسببه شبد، اما ا پیچ ای 3×24M برای پروژه استفاده شدهاسهد دلیل آن محاسبات اجزاء ميباشد که در بخش ای بعدی انجان شدهاسهد روی يک ورق با ضخامه 30 نميتوان پیچ 10 بسهد

فصل چهارن: محاسبات پیچ و پین 9

### 4.8 پیچ ای نبشي )قسمه ابتدايي شاخک(

ال ن به ذکر اسبه با اين که پیچ ای 1.5×10M برای اين قسبمه محاسببه شبد، اما ا پیچ ای 3×24M برای پروژه استفاده شدهاسهد دلیل آن محاسبات اجزاء ميباشد که در بخش ای بعدی انجان شدهاسهد روی يک ورق با ضخامه 30 نميتوان پیچ 10 بسهد

فصل چهارن: محاسبات پیچ و پین 10

پیچ ای بین دو ورق

4

9

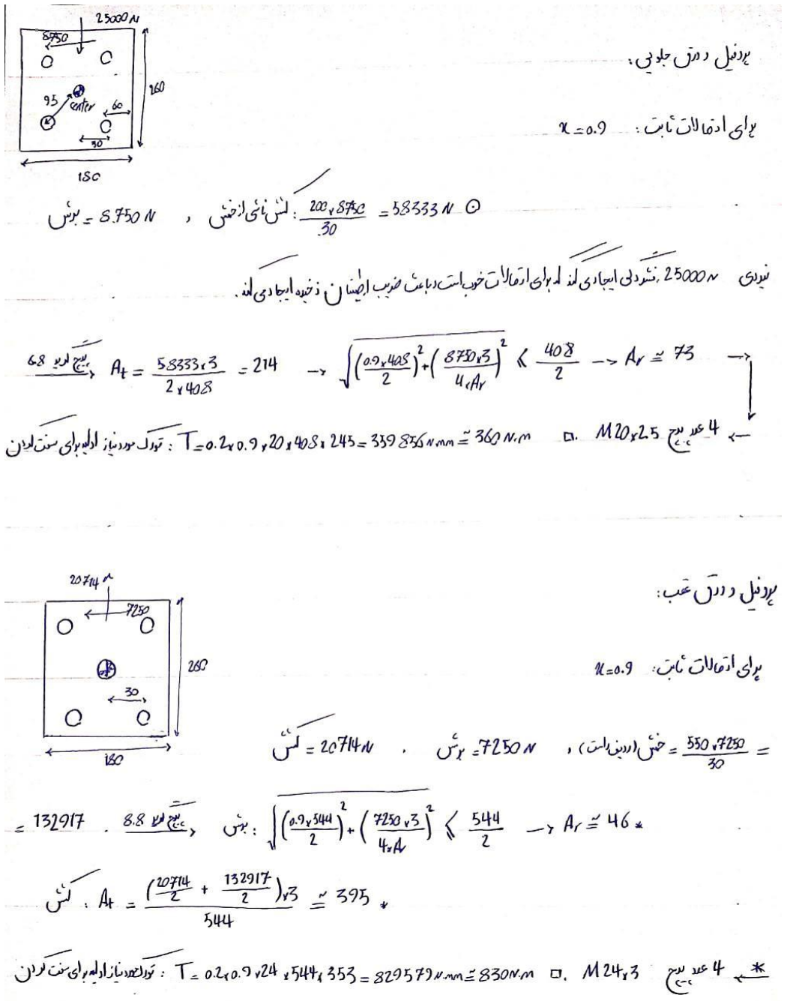
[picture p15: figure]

فصل چهارن: محاسبات پیچ و پین 11

### 4.10 پیچ ای بین دکل و چهار عدد ورق

فصل پنج : محاسبات جوش 12

## 5 محاسبات جوش

### 5.1 جوش دو عدد ناوداني

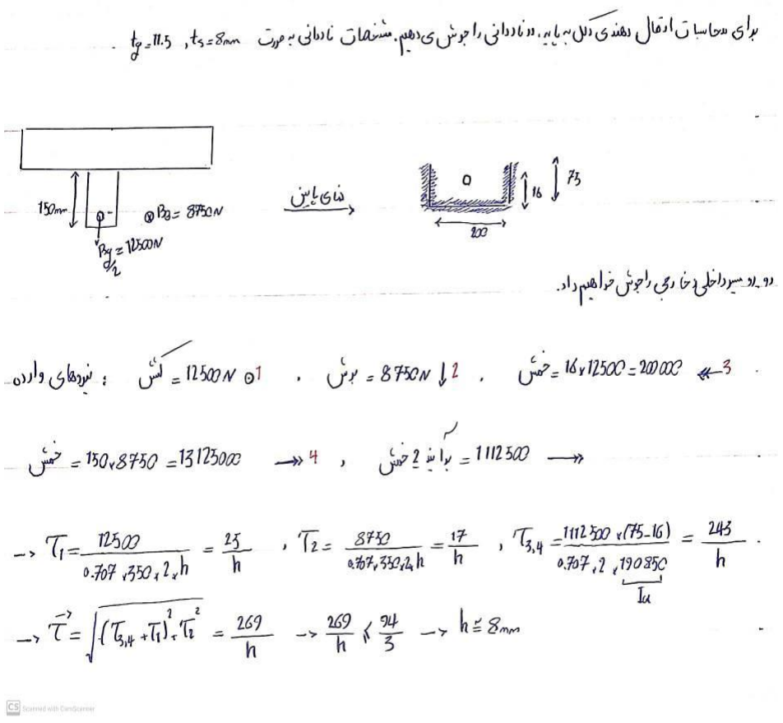
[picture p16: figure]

5. ير دکل | فصل پنج : محاسبات جوش 13

2

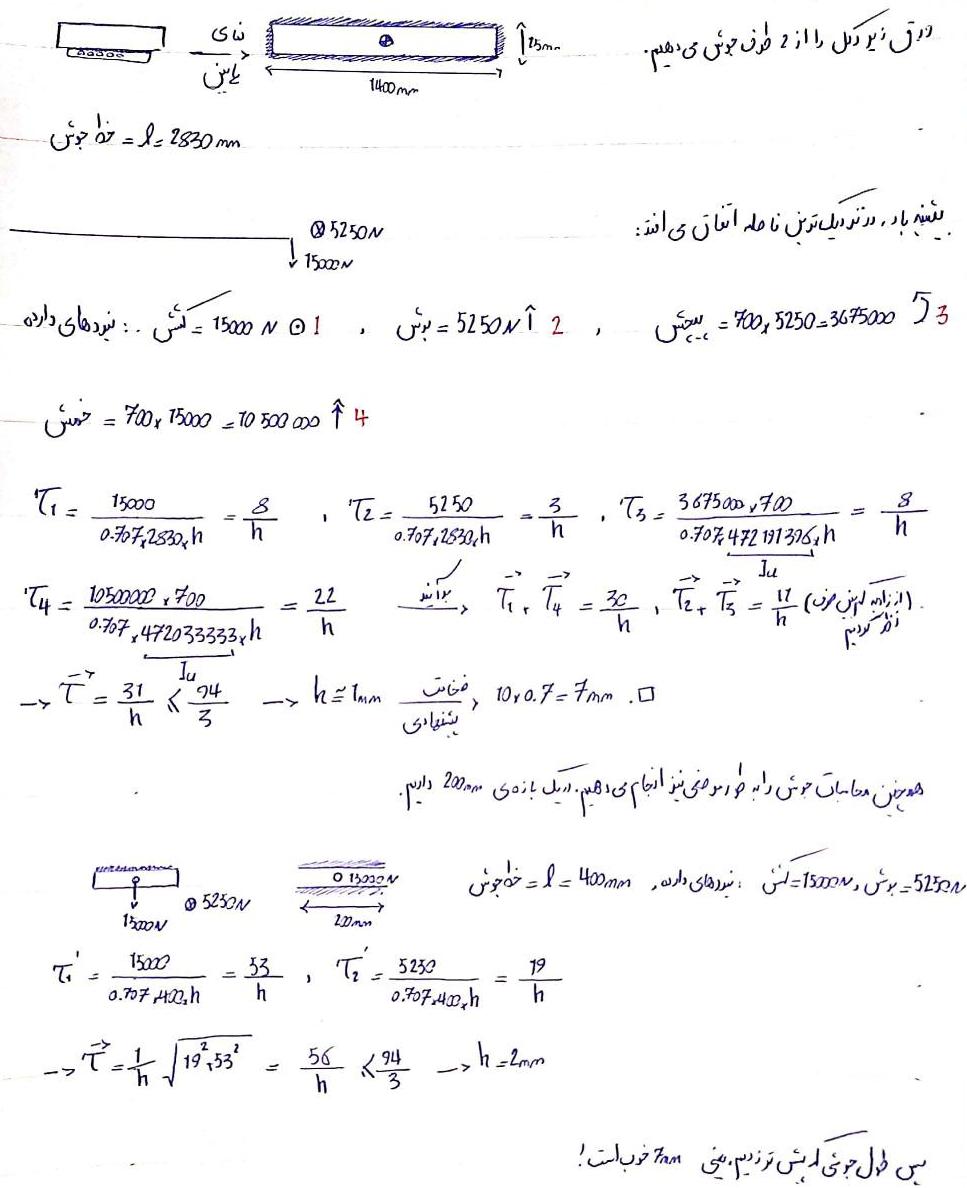
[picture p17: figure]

5. جوش نبشي به پروفیل روی شاخک | فصل پنج : محاسبات جوش 14

3

فصل پنج : محاسبات جوش 15

### 5.4 جوش ورق ير پروفیل ای جلو و عقب

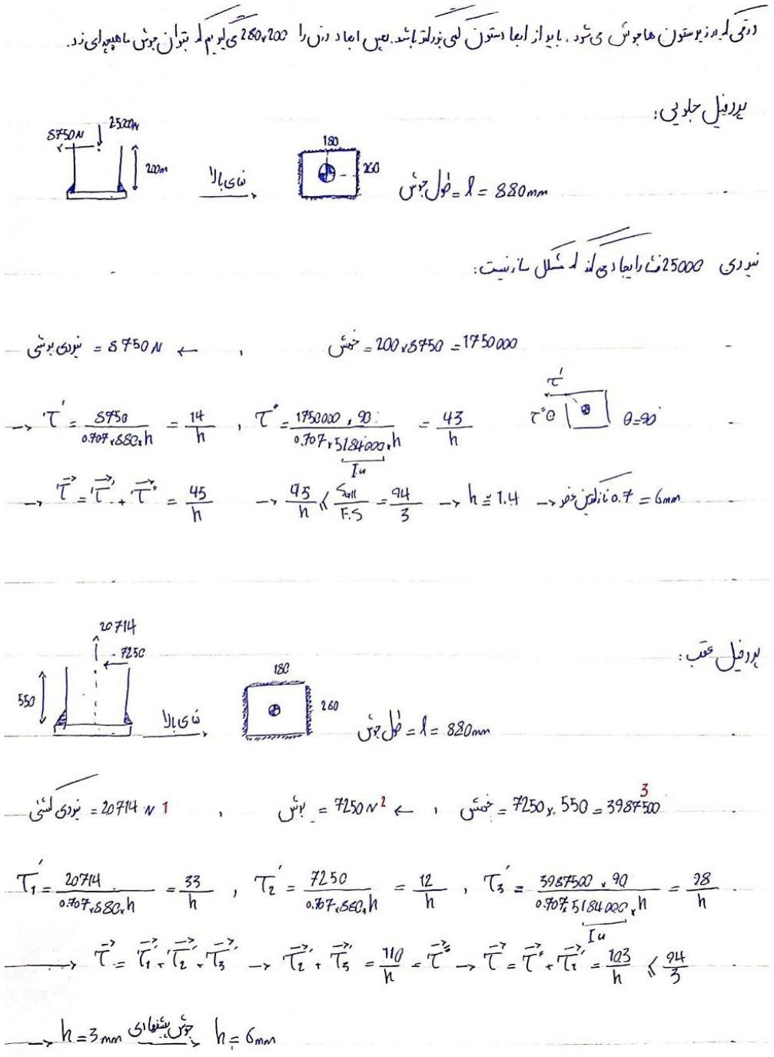
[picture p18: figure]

فصل پنج : محاسبات جوش 16

### 5.5 جوش بین پروفیل مربعي و ورق در انتها

فصل پنج : محاسبات جوش 17

### 5.6 جوش بین ورق آخر پروفیل داخل دکل

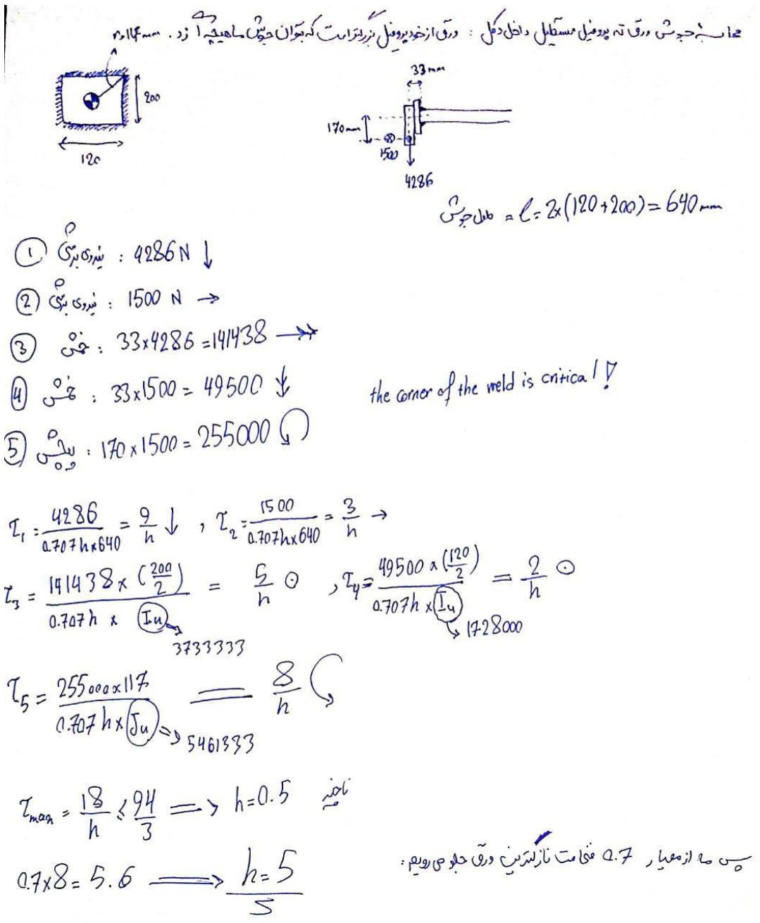
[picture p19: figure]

5. جوش دسته | فصل پنج : محاسبات جوش 18

7

## 6 محاسبات مقاومه اجزاء

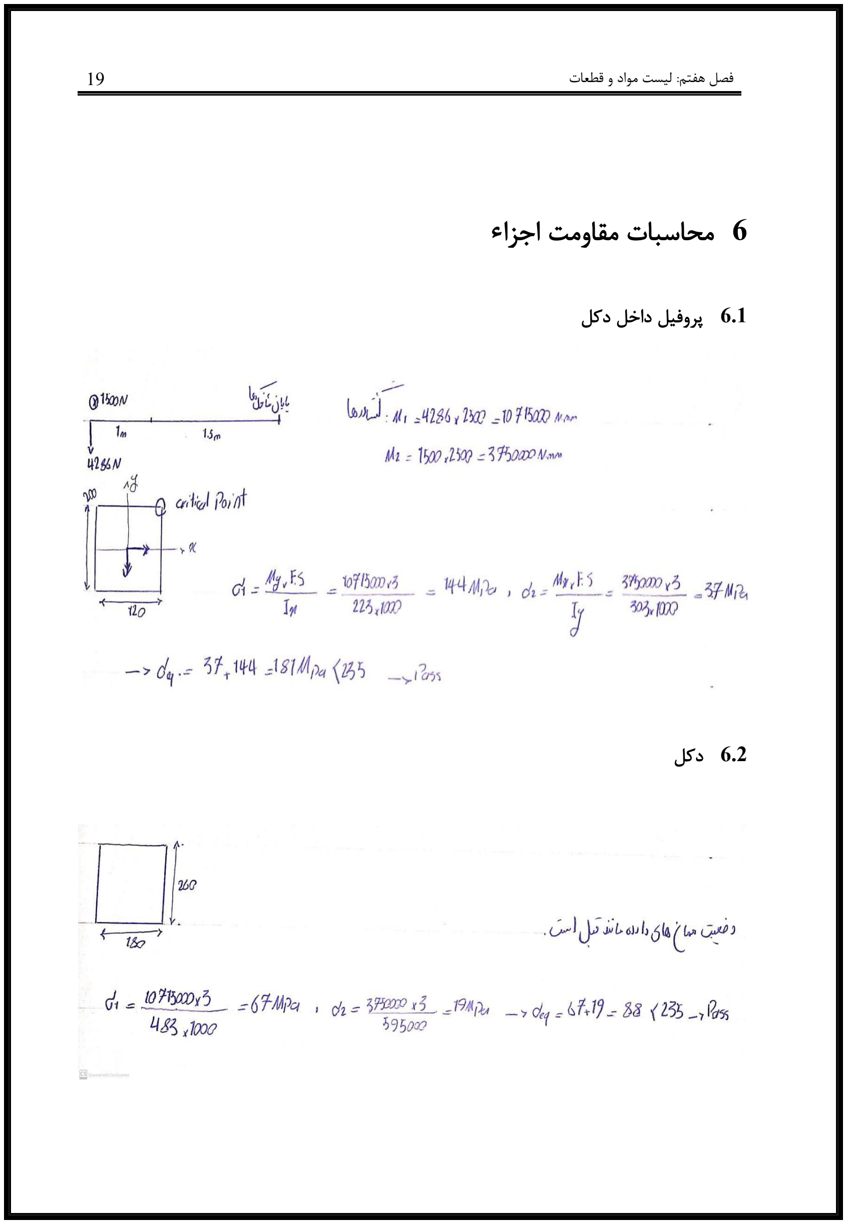
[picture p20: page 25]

فصل فت : لیسه مواد و قطعات 19

### 6.1 پروفیل داخل دکل

### 6.2 دکل

### 6. ناوداني فصل فت : لیسه مواد و قطعات 20

3

6. ورق جلويي )روی نبشي ا( | فصل فت : لیسه مواد و قطعات 21

4

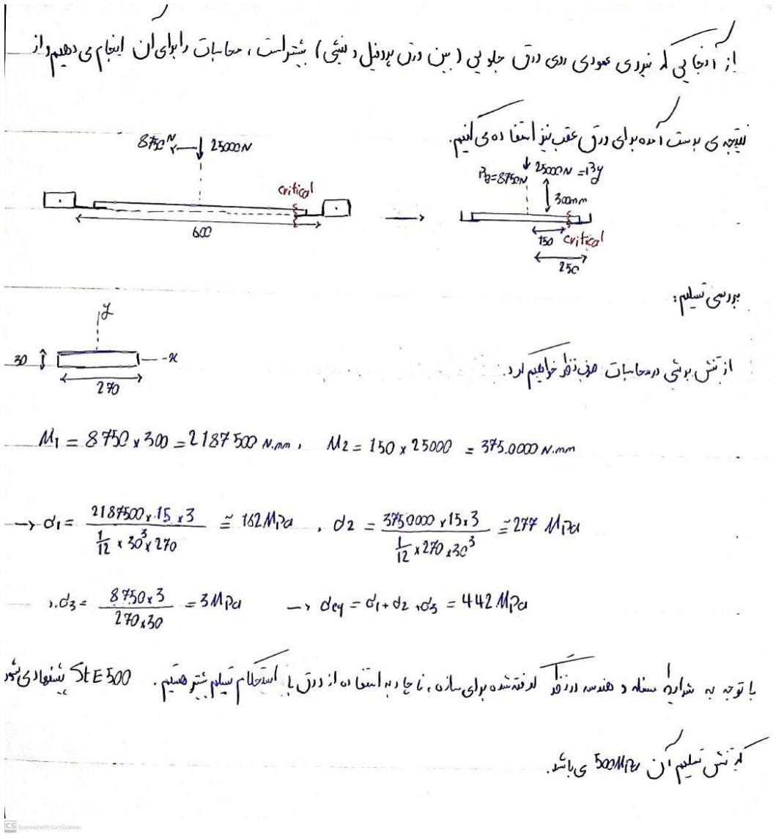
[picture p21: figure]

6. ورق پشتي )روی نبشي ا( | فصل فت : لیسه مواد و قطعات 22

5

فصل فت : لیسه مواد و قطعات 23

### 6.6 ستون ای متصل به پین A و پیچ B

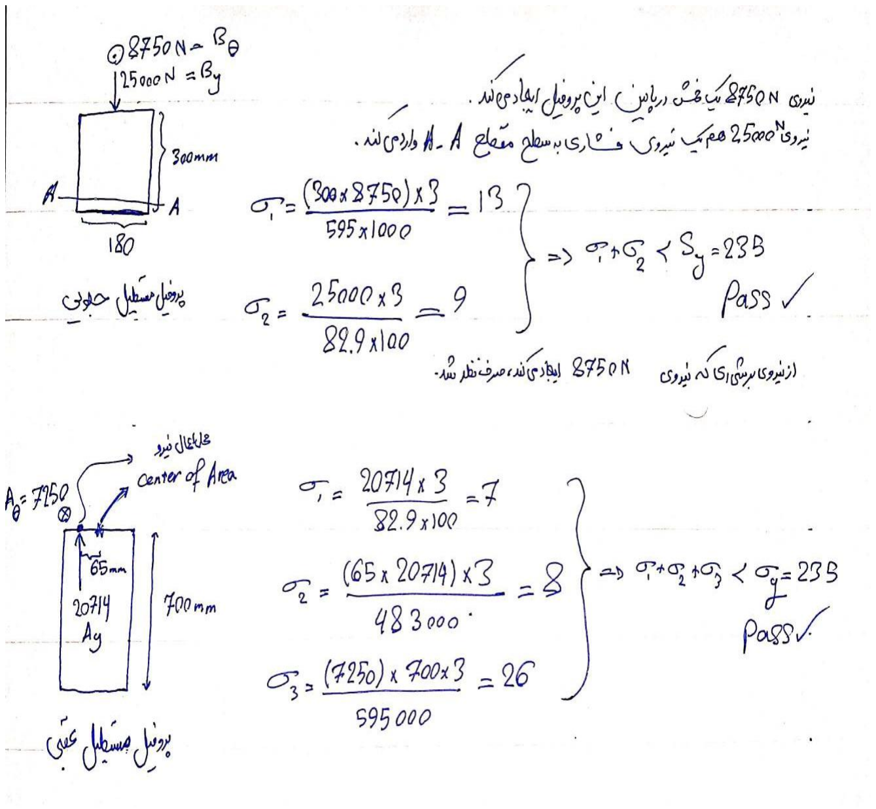
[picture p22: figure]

### 6.7 باقي اجزاء

در مورد نبشبي ا، ا محاسبباتي که برای جوش در آن قسبمه شبد ضبخامه نبشبي ا بدسبه آمدد مننین با توجه به ابعاد شباخک ای لیفه تراک، اندا ه پروفیل ای روی آن ا نتیجه شبدد بعالوه در قسبمه ای محاسبه پیچ، لهیدگي نیز برای اجزا در آن نواحي حساب شدندد

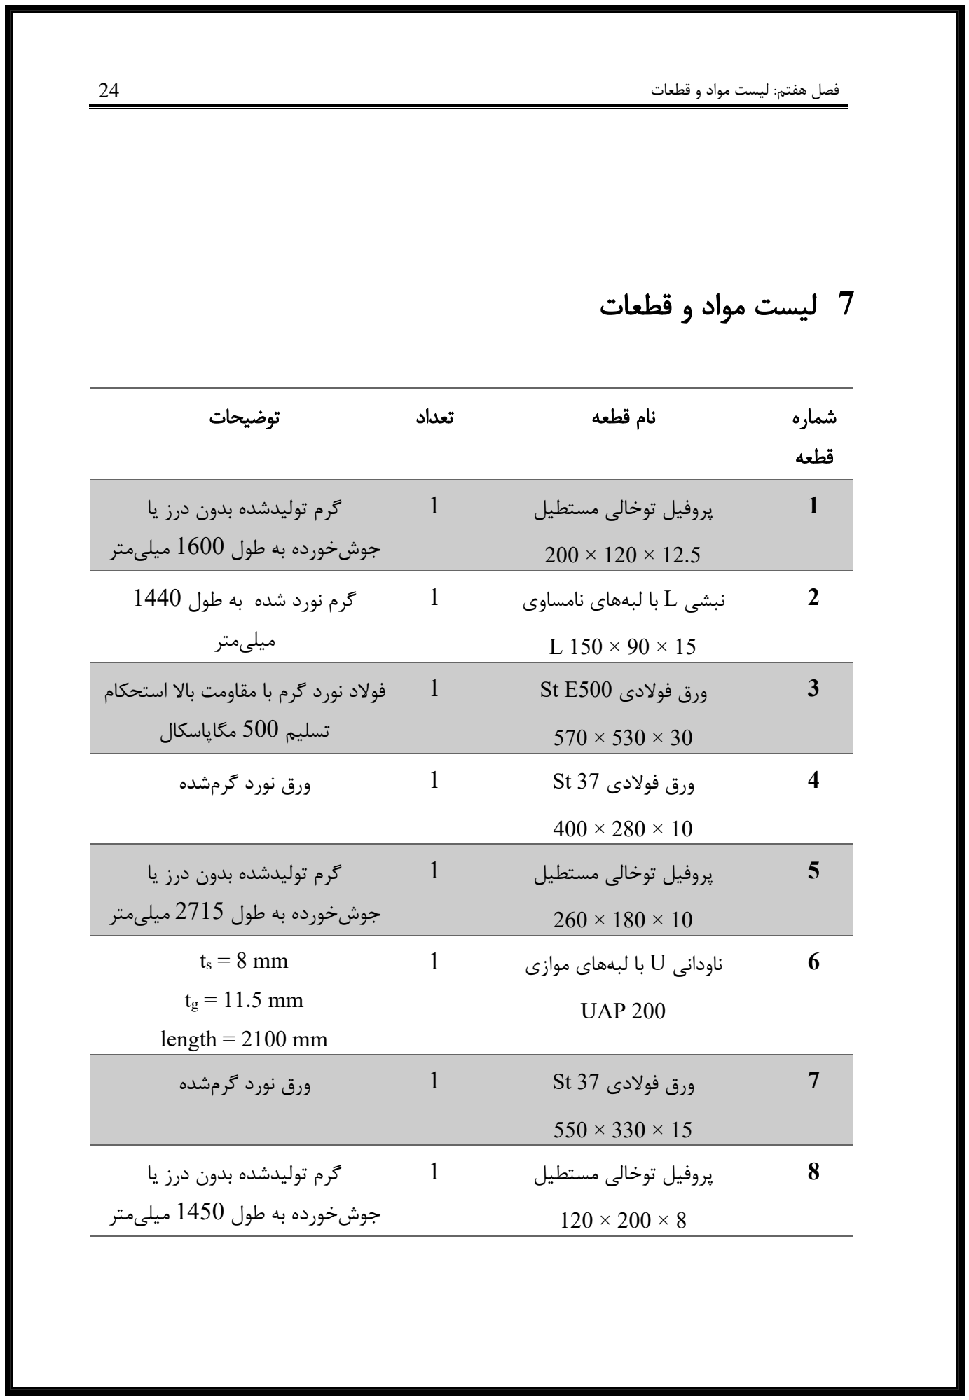
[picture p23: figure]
فصل فت : لیسه مواد و قطعات 24; 7 لیسه مواد و قطعات; شماره قطعه; نان قطعه تعداد توضیحات; 1 پروفیل توخالي مستطیل; 1 گرن تولید شده بدون در يا جوش خورده به طوک 1600 میلي متر; 2 نبشي L با لبه ای نامساوی; 1 گرن نورد شده به طوک 1440 میلي متر; 3 ورق فوالدی 500E St; 1 فوالد نورد گرن با مقاومه باال استحكان تسلی 500 مگاپاسكاک; 4 ورق فوالدی 37 St; 1 ورق نورد گرن شده; 5 پروفیل توخالي مستطیل; 1 گرن تولید شده بدون در يا جوش خورده به طوک 2715 میلي متر; 6 ناوداني U با لبه ای موا ی; UAP 200; length = 2100 mm; 7 ورق فوالدی 37 St; 8 پروفیل توخالي مستطیل; 1 گرن تولید شده بدون در يا جوش خورده به طوک 1450 میلي متر

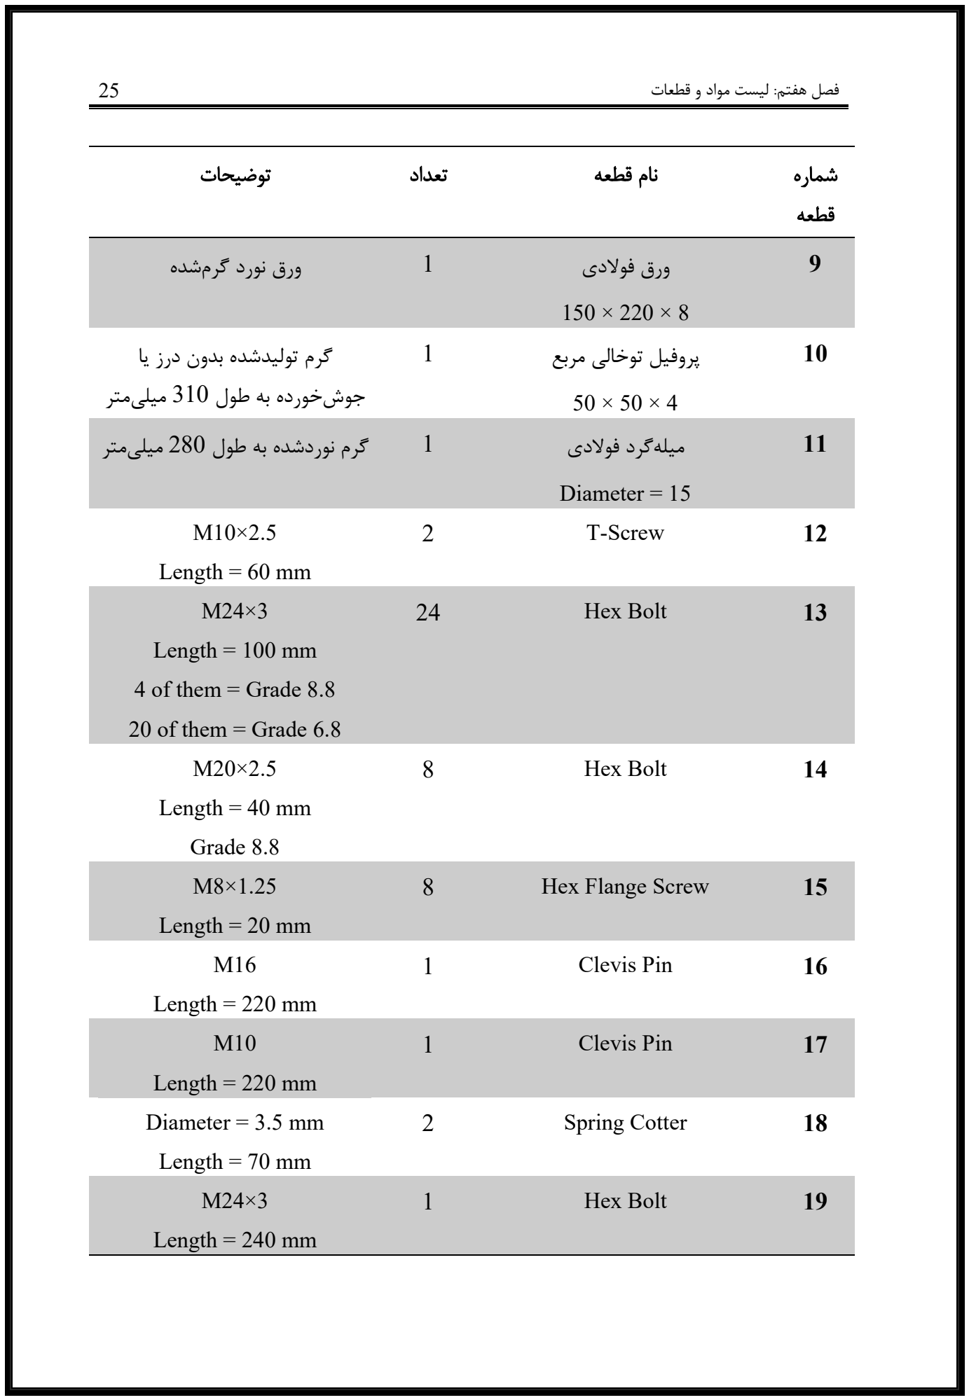
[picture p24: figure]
فصل فت : لیسه مواد و قطعات 25; شماره قطعه; نان قطعه تعداد توضیحات; 9 ورق فوالدی; 1 ورق نورد گرن شده; 10 پروفیل توخالي مربع; 1 گرن تولید شده بدون در يا جوش خورده به طوک 310 میليمتر; 11 میله گرد فوالدی; Diameter = 15; 1 گرن نورد شده به طوک 280 میليمتر; T-Screw; Length = 60 mm; Hex Bolt; Length = 100 mm; 4 of them = Grade 8.8; 20 of them = Grade 6.8; Length = 40 mm; Grade 8.8; Hex Flange Screw; Length = 20 mm; Clevis Pin; Length = 220 mm; Diameter = 3.5 mm; Spring Cotter; Length = 70 mm; Length = 240 mm

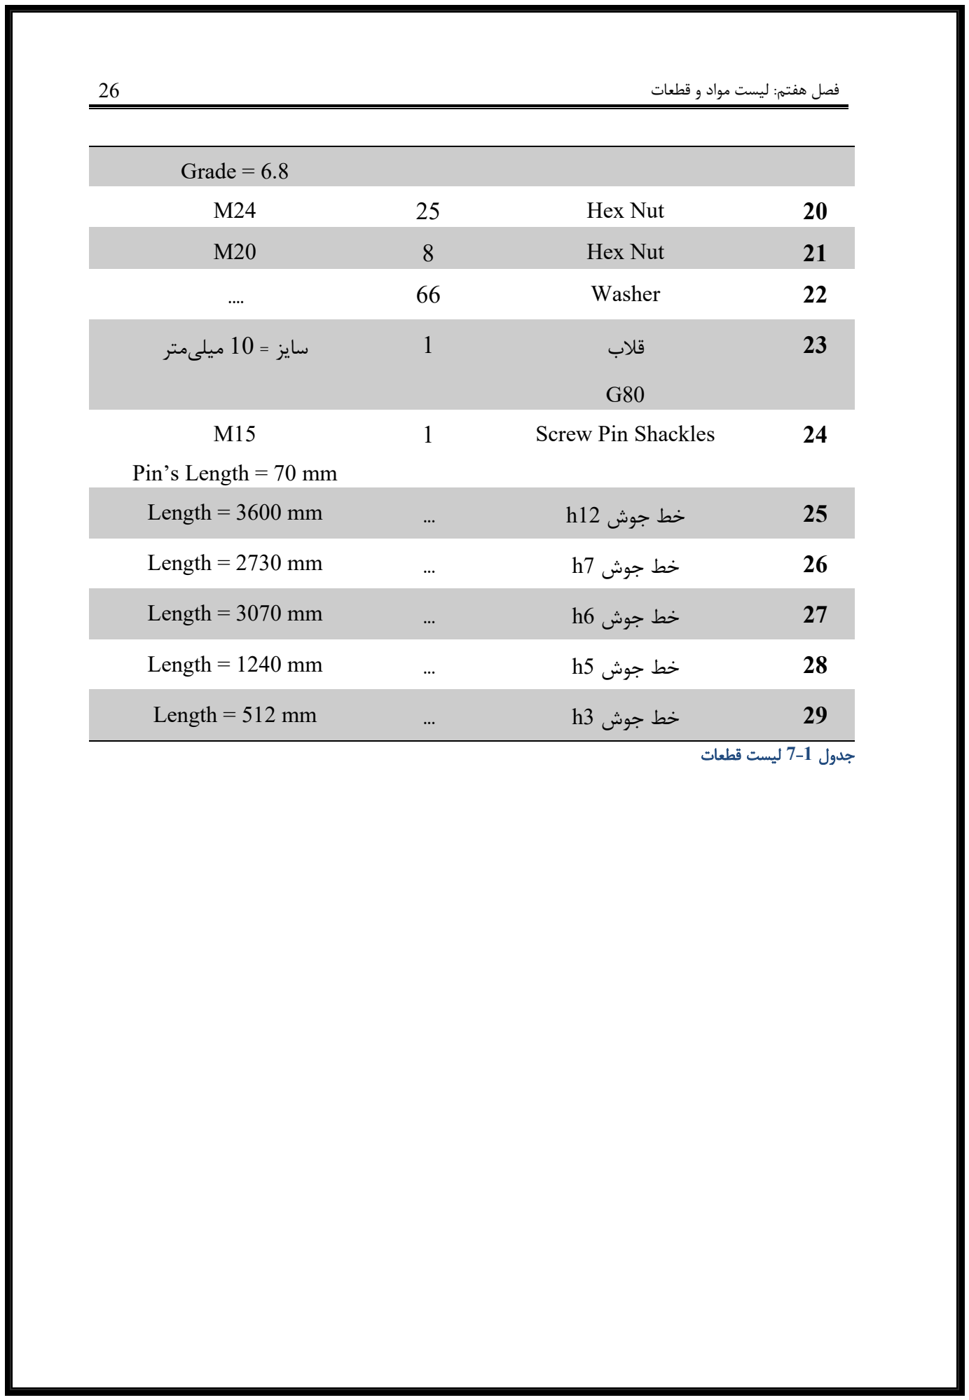
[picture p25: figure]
فصل فت : لیسه مواد و قطعات 26; Grade = 6.8; Hex Nut; 22 Washer 66 دددد; 23 قالب; 1 سايز = 10 میلي متر; Screw Pin Shackles; Pin’s Length = 70 mm; 25 خط جوش 12h ددد mm 3600 = Length; 26 خط جوش 7h ددد mm 2730 = Length; 27 خط جوش 6h ددد mm 3070 = Length; 28 خط جوش 5h ددد mm 1240 = Length; 29 خط جوش 3h ددد mm 512 = Length; جدوک 7-1 لیسه قطعات

8.1 دکل | 8 نقشه ا | فصل شت : نقشه ا 27

8. پروفیل داخل دکل | فصل شت : نقشه ا 28

2

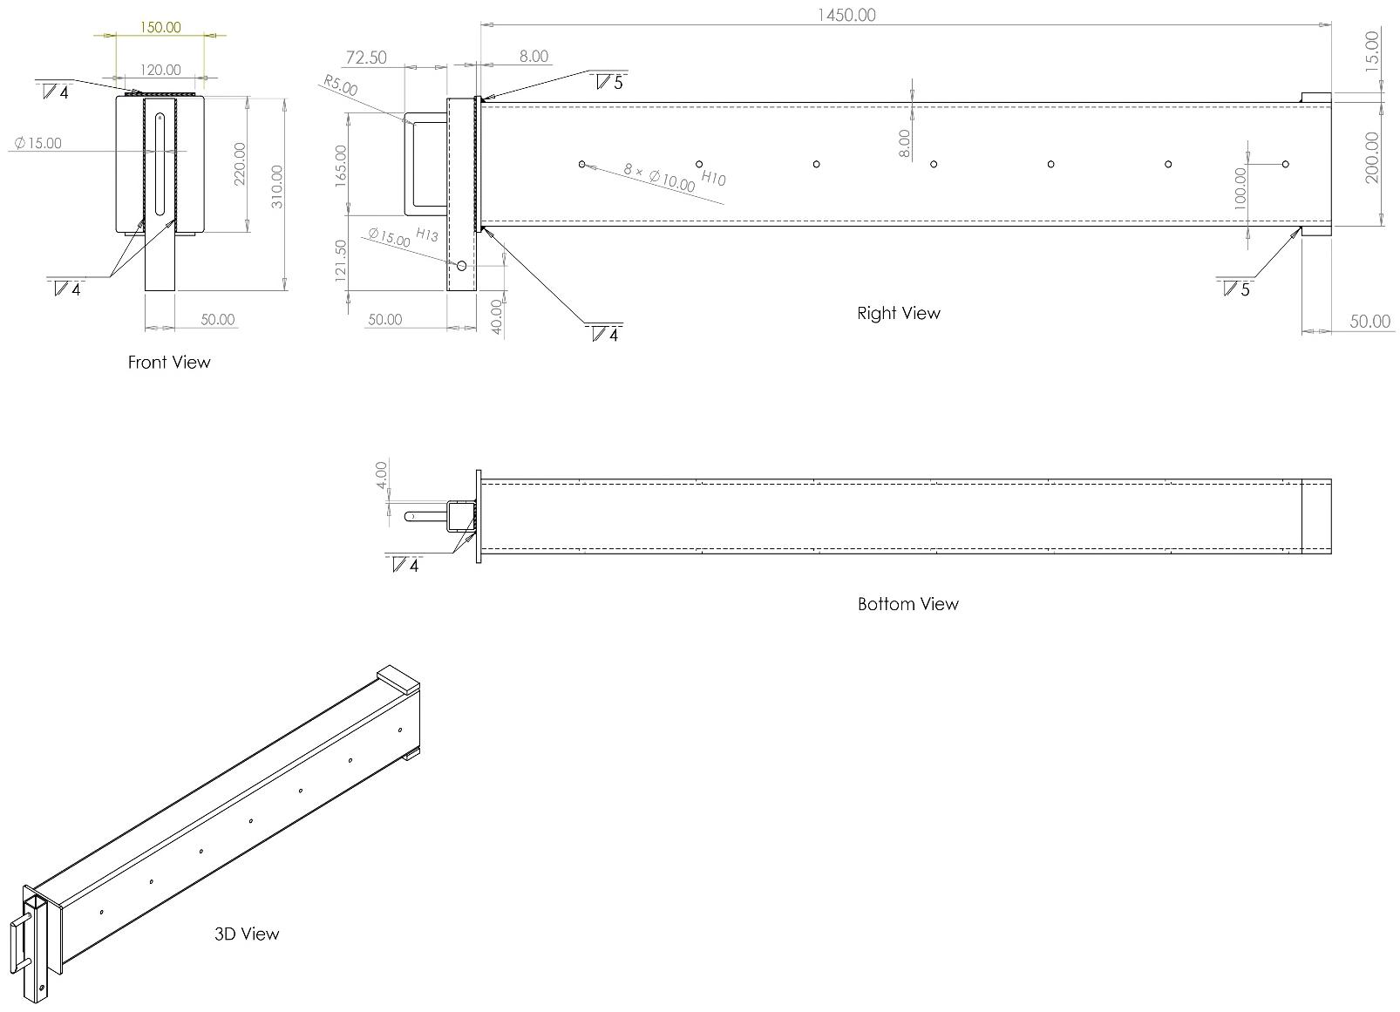
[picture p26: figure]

فصل شت : نقشه ا 29

### 8.3 قاب

در اين قسمه اجزاء مختلف قاب ير شمارهگذاری و در پنج نقشهی مختلف قرار داده شدندد

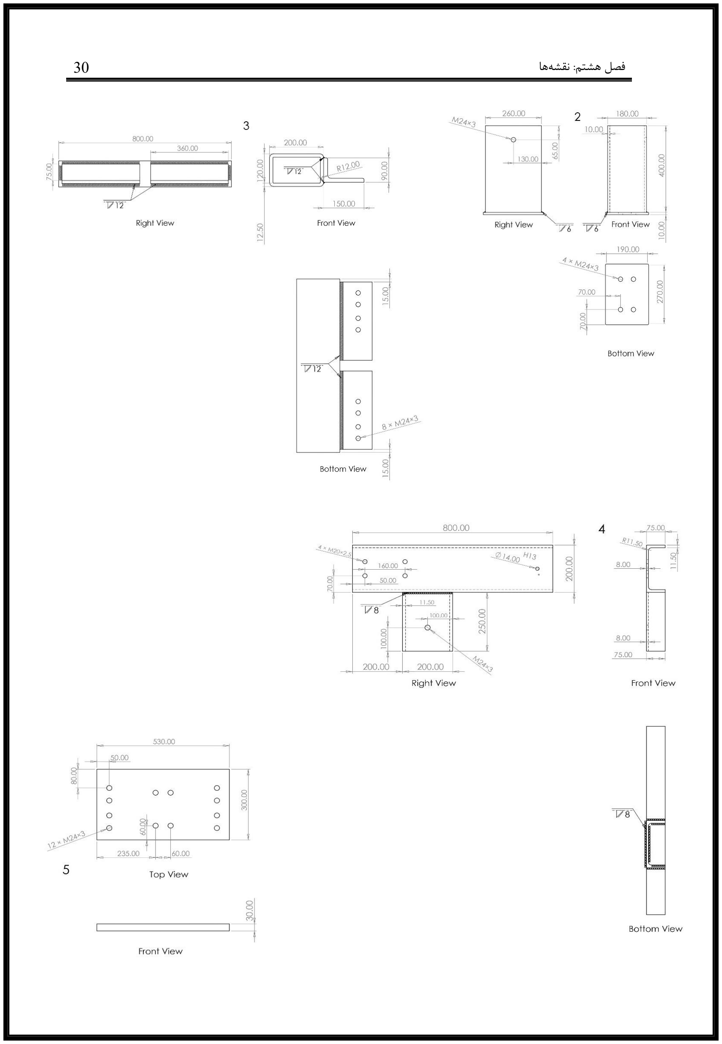
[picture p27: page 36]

فصل شت : نقشه ا 30

فصل شت : نقشه ا 31

### 8.4 حاله ای قرارگیری سا ه

در نقشه ای ير ر يک ا حاله ای قرارگیری دکل نسبه به قاب لحاظ شدندد


فصل شت : نقشه ا 32

فصل شت : نقشه ا 33

فصل نه : کاتالوگ محصوک 34

## 9 کاتالوگ محصوک


فصل نه : کاتالوگ محصوک 35

| | شماره جزء نان جزء تعداد
| | 1 پروفیل پايه 2
| | 2 پروفیل پشتي 1
| | 3 پروفیل جلويي 1
| | 4 اتصاکد نده 2
| | 5 ورق يرين 2
1 | Boom | 6
1 | Inner Extension Tube | 7
2 | Right (left) liner | 8
2 | Down (up) liner | 9
24،24،48 | Bolt, Nut and Washer | 10
8،8،16 | Bolt, Nut and Washer | 11
1،1،2 | Bolt, Nut and Washer | 12
8 | Hex Flange Screw | 13
2 | T-Screw | 14
1،1 | Pin and Spring Cotter Pin | 15
1،1 | Pin and Spring Cotter Pin | 16
Part List 9-1 | جدوک

فصل د : روش مونتاژ 36

## 10روش مونتاژ

اين سبا ه بصبورت کامل قابل مونتاژ کردن و دمونتاژ کردن اسبهد در اين قسبمه نحوه مونتاژ دکل جرثقیل بر روی لیفتراک و امكان قراردادن قطعات در يک جعبه به ابعاد دکل، بررسي ميشودد ابعاد جعبه برابر با ابعاد دکل ميباشبدد جرثقیل با اسبتفاده ا پیچ و در نیر گرفتن فاصبله قطعات
ا ، به گونهای طراحي شبده که یچ قطعهای ا محدوده مشبخ شبده تجاو نكندد با توجه به لیسبه قطعات )فصل فت ( مشخ ميشود که تمامي اجزا در اين جعبه جا ميشوندد در ابتدای کار بايد قاب مونتاژ شبودد قبل ا قرار دادن اجزا در جعبه تمامي جوش ا روی قطعات
با قوس الكتريكي ده شببدندد ابتدا 16 عدد پیچ 3×24M بین ورق 500E St و نبشببي ايي ا قبل به پروفیل جوش 12h ده شبده، نصبب ميشبوندد تا اينجای کار قسبمه پايیني قاب آمادهاسبهد بعد ا آن، ستون ا )پروفیل ای عمود بر راستای شاخک( که به ورق ای ا جنس 37 St و ضخامه 10 میليمتر ا قبل جوش 6h داده شببدند، با اسببتفاده ا شببه عدد پیچ 3×24M بین دو ورق بكاررفته با جنس ای مختلف سبفه ميشبوندد در مورد بسبتن مهره ا، فضبا برای بسبتن مهره و واشبر روی تمان پیچ ا به اندا ه کافي وجود داردد با اتمان مونتاژ قاب ميتوان آن را بر روی لیفتراک سببوار کردد به اين صببورت که قاب را روی مین گذاشبته و با حرکه دادن لیفتراک به سبمه جلو، پروفیل ای طراحي شبده، روی شباخک ا مينشبینندد در انتها دو عدد Screw-T با مشبخصبات 1.5×10M بین ر يک ا شباخک ا و پروفیل برای ت بیه آن نصب ميشوندد
حاال نوبه به مونتاژ دکل و پروفیل داخل آن اسبهد ابتدا دکل که يک ورق طويل فوالدی با عرض
ک را ير آن ا قبل جوش دادي ، روی میزکار گذاشببته شببده و پروفیل داخلي که قطعات آن قبال به جوش داده شبدند به داخل دکل برده ميشبود و تا نصف طوک پروفیل وارد دکل ميشودد ال ن به ذکر اسه که قطعات جوش داده شبببده )ا قبل( به پروفیل داخلي عبارتند ا يک ورق با صبببخامه ،8 يک پروفیل مربعي و يک میلهگرد فوالدی که خ شبده تا شبكل يک دسبته را بگیردد سبهس چهار عدد ورق با ضبخامه 15 بین فضببای دکل و پروفیل داخلي قرار داده و شببه عدد پیچ 1.25×8M را در چهار طرز انتهای دکبل ببه اين چهبار ورق پیچ ميکنی د ببا اين کبار ميتوان پروفیبل را تبا جبايي کبه سبببوراخ آخر برای آن ده شده )يا حتي بیشتر( داخل برد و پین C را با قطر 10 در انتهای دکل وارد کردد برای خاتمهی اين بخش، اشهیل فنری تهیهشده بايد در پین قرارداده ميشودد

فصل د : روش مونتاژ 37

در مرحلهی بعدی به سببراا اتصبباک د نده ا که خود ا جوش دو ناوداني تهیه شببدهاند خوا ی
رفهد قاب و دکل مونتاژشبده، در ارتفاعي مناسبب نسببه به ، روی سبطوحي صباز قرار داده ميشبوند تا بتوان ر دو نباوداني را ببه دوطرز دکبل پیچ کردد برای اين مه ، در ر طرز چهبار عبدد پیچ 2.5×20M تهیه شبدهاند که بین دکل و ناوداني پیچ ميشبوندد سبهس، پین A به قطر 14 میليمتر با اشبهیل فنری و پیچ B با مشبخصبات 3×24M در نواحي تعیین شبده بترتیب بین ناوداني و سبتون عقبي و بین ناوداني و ستون جلويي نصب ميشوندد
در پايان، Shackles Pin Screw و قالب 80G در سبوراخ مورد نیر قابل نصبب اسبهد به عالوه،
حاال ميتوان دکل را در اويه ای مختلف تنیی کردد برای اين کار بايد پین A در سببوراخ ای مختلف گذاشبته شبودد مننین، میتوان طوک دکل را با جابجا کردن پین C و اسبتفاده ا دسبتهی انتهای دکل ياد يا ک کردد

فصل يا د : برآورد قیمه 38

## 11برآورد قیمه قطعات سا ه جرثقیل )نرخ رو با ار ايران(

در اين گزارش قیمه رو ر يک ا قطعات فوالدی و اتصباالت ارائهشبده توسبط کاربر محاسببه شبده و سببهس زينه جوشببكاری و جمع کل قیمه سببا ه برآورد ميگرددد قیمه ا به تومان و مطابق نرخ ای اواخر ارديبهشبه و اوايل خرداد ۱۴۰۴ ا منابع معتبر اسبتخرا شبدهاندد منابع قیمه ا در کنار ر مورد ذکر شده اسه.

### 11.1 قیمه رو قطعات فوالدی

جدوک ير قیمه واحد )کیلويي يا عددی( و قیمه کل رقطعه را نشبببان ميد دد برای پروفیل ا و ورقه اای فوالدی، قیمه بر اسباس کیلوگرن محاسببه شبده اسبهد برای پیچ و مهره ا قیمه حدودی بر اسباس و ن يا عدد ذکر شببده اسببه پیچ و مهره ا عموما بهصببورت کیلويي فروخته ميشببوند تمامي قیمه ا با احتساب مالیات بر ار ش افزوده به تومان ميباشند . قیمه پروفیل ای صبنعتي سبنگین )رديفهای 1، 5 و 8( در با ار امرو حدودا بین ۴۲ تا ۵۰ زار
تومان به ا ای رکیلو متغیر اسبهد برای م اک، پروفیل ۲۰۰ در ۲۰۰ ضبخامه ۸ الي ۱۰ میل حدود ۴۵ تا ۵۰ زار تومان/کیلو معامله ميشبود د مننین نبشبي سبنگین ۱۵ میلیمتری )رديف 2( بر اسباس قیمه نبشبي ۱۵۰×۱۵۰ مشبابه، حدود ۵۴ زار تومان بر کیلو در نیر گرفته شبده اسبه د قیمه ورق ا بسبتگي به آلیاژ و ضبخامه دارد؛ ورق 52St( رديف 3( کمي گرانتر ا ورق معمولي 37St اسبه )حدود ۴۴ –۴۶ زار تومبان/کیلو در مقباببل ~۴۰ زار تومبان/کیلو برای ورق سبببیباه معمولي(د پیچ و مهره بای فوالدی بر اسباس تخمین و ني قیمهگذاری شبدهاند، يرا اين اقال عمدتا کیلويي عرضبه ميشبوند د برای پیچ ای خشبكه کالس ۸٫۸ متوسبطا کیلويي ~۶۰٬۰۰۰ تومان )بدون مالیات( در نیر گرفته شبده اسبه که معادک م ال ~۳۰٬۰۰۰ تومان برای ر پیچ 24M ميباشد د

فصل يا د : برآورد قیمه 39

شبببرح قبطبعبه و شماره مشخصات | طبوک / ابعاد | و ن تقريبي | قببیببمببه واحببببببد )تومان( | قبیبمبه کبل )تومان( | منبع قیمبه / توضیح
پبروفبیبل قبوطبي 1 مسبببببتببطببیببل 12.5 ×120×200 )طوک 1.6 متر( | 1.6 متر | 98 کیلوگرن | | | پبببروفبببیبببل 4,825,000~ 50,000~ صببببنبعبتبي سنگین
نبشبي باکنامسباوی 2 15×90×150 )طوک 1.44 متر( | 1.44 متر | 38 کیلوگرن | | | نبشي سنگین 2,065,000~ 54,300~
ورق فببوالدی ST 3 E500 (ST52) ابببببببببعبببببببباد 30 ×530×570 میليمتر | - 71 | کیلوگرن | | | ورق آلبیباژی 3,230,000~ 44,360~ اکسین ا وا
ورق 37St ابببعبباد 4 10 ×280×400 mm | - 8.8 | کیلوگرن | | | ورق سبیاه ۱۰ 370,000~ 40,000~ میل
پروفیبل مسبببتطیبل 5 10 ×180×260 )طوک 2.715 متر( | 2.715 متر | 179 کیلوگرن | | | پبببروفبببیبببل 8,820,000~ 50,000~ صببببنبعبتبي سنگین
ناوداني 200 UAP 6 طوک 2.1 متر | 2.1 متر | 61 کیلوگرن | | | نبببباودانببببي 2,760,000~ 45,000~ سنگین
ورق 37St ابببعبباد 7 15 ×330×550 mm | - 21.4 | کیلوگرن | | | ورق سبیاه ۱۵ 880,000~ 40,000~ میل

فصل يا د : برآورد قیمه 40

پروفیبل مسبببتطیبل 8 8 ×200×120 )طوک 1.45 متر( | 1.45 متر | 59 کیلوگرن | پبببروفبببیبببل 2,920,000~ 50,000~ صنعتي
ورق 37St ابببعبباد 9 mm8×220×150 | - 2.1 | کیلوگرن | ورق سبببیاه ۸ 85,000~ 40,000~ میل
قببوطببي مببربببع 10 50×50×4 )طببوک 0.31 متر( | 0.31 متر | 1.8 کیلوگرن | پروفیل سبک 75,000~ 42,000~
میلگرد فوالدی قطر 11 15مبیبلبيمبتبر طبوک 28 سانتيمتر | 0.28 متر | 0.39 کیلوگرن | میلگرد ساده 14,000~ 35,000~
پبیبچ T شببببكبل 12 2.5×10M طببوک 60 میليمتر | | 3,000~ 2عدد ر عدد | تبخبمبیبنبي 6,000~ -براسبباس و ن g3
پبیبچ شبببشگبوش 13 خشبببكبه 3×24M طوک 100میبليمتر کالس 8.8 | 24 عدد | ~30,000 ر عدد | و ن 720,000~ -/0.45kgپبیبچ 60,000 ×
پبیبچ شبببشگبوش 14 خشبكه 2.5×20M طبببوک 40 mm کالس 8.8 | | 9,000~ 8عدد ر عدد | و ن 72,000~ -/0.15kgپیچ
پبیبچ شبببشگبوش 15 واشببببببببببببردار 1.25×8Mطببوک 20 mmفلنجي | | 1,000~ 8عدد ر عدد | و ن 8,000~ -/18gپیچ

فصل يا د : برآورد قیمه 41

پببیببن فببوالدی 16
Clevis قببطببر
16Mطبببببوک
mm220

و ن 20,000~ - 20,000~ 1عدد

kg × 0.35
60,000

جدوک 11-1 قیمه قطعات

### 11.2 زينه جوشكاری سا ه

طبق اطالعات ارائهشبده، طوک کل خطوج جوشبكاری در اين سبا ه حدودا برابر اسبه با ۶۰۷۵ میليمتر )جمع مقادير انتهای جدوک قطعات: ۱۶۰۰ + ۲۷۱۵ + ۱۴۵۰ + ۳۱۰(د اين خطوج جوش احتماال در ای جوش گوشبه )فیله( با ضبخامه ای مختلف )با توجه به ضبخامه قطعات متصبلشبونده( سبتندد زينه جوشبكاری دسبتي با الكترود SMAW به ا ای ر متر جوش بر اسباس ضبخامه جوش متفاوت اسبهد در با ار فعلي، به صورت عرز ميتوان نرخ ايي تقريبي به صورت ير در نیر گرفه:
- جوش سايز ۴–۵ میليمتر حدود ~۳۰٬۰۰۰ تومان به ا ای ر متر جوش
- جوش سايز ۶ میليمتر: حدود ~۵۰٬۰۰۰ تومان به ا ای ر متر جوش
- جوش سببايز ۸ میليمتر )جوش سببنگینتر برای مقاطع ضببخی (: حدود ~۶۰٬۰۰۰ تا ۷۰٬۰۰۰ تومان به ا ای ر متر جوش

برای دقه بیشببتر، میتوان جزء به جزء نیز برآورد کردد م ال اگر ا ۶٫075 متر جوش، حدود ۴٫315 متر جوش ای سبنگین ۸ میليمتری )رديفهای 1 و 5( و 1٫45 متر جوش متوسبط ۶ میليمتری )رديف 8( و 0٫31 متر جوش سبک ۴ میليمتری )رديف 10( باشد، زينه را چنین تخمین مي نی :
- جوش ۸ میليمتر: ۴٫315 متر × ۶۰٬۰۰۰ تومان/متر ≈ ۲۵۸٬۹۰۰ تومان
- جوش ۶ میليمتر: ۱٫45 متر × ۵۰٬۰۰۰ تومان/متر ≈ ۷۲٬۵۰۰ تومان
- جوش ۴ میليمتر: ۰٫31 متر × ۳۰٬۰۰۰ تومان/متر ≈ ۹٬۳۰۰ تومان

جمع زينبه جوشبببكباری ≈ ۳۴۰٬۷۰۰ تومبان )تقريببا ۰٫۳۴ میلیون تومبان(د اين رق ترا برآورد کلي قبلي )حدود ۰٫۳ تا ۰٫۴ میلیون تومان( اسبهد در عمل ممكن اسبه با در نیر گرفتن دسبتمزد رو انه

فصل يا د : برآورد قیمه 42

جوشبكار و زينه الكترود، قیمه نهايي اندکي تغییر کندد اما مقدار محاسببهشبده، برآورد مناسببي ا زينه جوشكاری کل سا ه با نرخ ای متداوک فعلي اسهد

### 11.3 محاسبه مقدار و زينه رنگ مورد نیا

با فرض ضبخامه رنگ خشبک ۱۰۰ میكرون بر روی سبطح ۱۲ مترمربع سبا ه و درنیر گرفتن راندمان پوشبشد ي ۵ مترمربع بر کیلوگرن )میانگین( و مننین ۱۰٪ اتالز )به دلیل پرت شبدن رنگ در حین اجرا، پاشش و غیره(، مقدار و زينه رنگ مورد نیا را ميتوان به شكل ير محاسبه کرد:
- محاسبببه مقدار رنگ: سببطح ۱۲ مترمربع تقسببی بر ۵ مترمربع بر کیلوگرن، ۲٫۴ کیلوگرن
رنگ برای پوشبش اليه ۱۰۰ میكروني نیا اسبهد با افزودن ۱۰٪ اضبافي جهه اتالز، مقدار
کل رنگ ≈ ۲٫۶۴ کیلوگرن برآورد ميشبببودد به عببارت ديگر حدود ۲٫۵ تا ۳ کیلوگرن رنگ دو جزئي ال ن اسه.
- زينه واحد به ا ای ر کیلوگرن: با توجه به قیمه ای ذکرشده، به طور متوسط ر کیلوگرن رنگ اپوکسبي پليآمید حدود ۳۰۰ تا ۳۲۰ زار تومان زينه دارد )در بسبتهبندی ای چند کیلويي اسبببتباندارد (د ما برای محباسبببببه دقیقتر عدد ۳۱۶٬۰۰۰ تومان به ا ای ر کیلوگرن )مطابق قیمه رنگ روناس در بسته ۴٫۸ کیلويي( درنیر میگیري .
- محاسبببه زينه کل: با نیا ~۲٫۶۴ کیلوگرن رنگ، زينه کل ≈ ۲٫۶۴ × ۳۱۶٬۰۰۰ تومان خوا د بود که معادک حدود ۸۳۰٬۰۰۰ تومان ميشببودد به بیان ديگر، برای رنگآمیزی اين سببا ه با ضببخامه مذکور تقريبا بايد نزديک به ۸۳۴ زار تومان زينه صببرز خريد رنگ اپوکسبببي پليآمید کردد البته در عمل با توجه به بسبببتهبندی ای موجود، احتماال بايد يک بسبته ۴ يا ۵ کیلويي تهیه شبود که قیمه آن حدود ۱٫۵ میلیون تومان اسبه، اما تنها بخشبي ا آن برای ۱۲ مترمربع مصرز خوا د شد و مابقي میتواند برای پوششهای بعدی يا تعمیرات نگهداری شودد

### 11.4 جمعبندی: قیمه تمانشده نهايي سا ه

ببا جمع کردن زينبه تمبامي قطعبات فوالدی )ا جبدوک بخش ۱( و زينبه جوشبببكباری )بخش ۲(، قیمبه تمانشده تقريبي اين سا ه جرثقیل لیفتراک به دسه ميآيد :
- مجموع قیمه قطعات فوالدی: حدود ۲۶٬۸۲۰٬۰۰۰ تومان )معادک ۲۶٫۸۲ میلیون تومان(

فصل يا د : برآورد قیمه 43

- زينه کل جوشكاری: حدود ۳۵۰٬۰۰۰ تومان )۰٫35 میلیون تومان )
- زينه رنگ: حدود 830000 تومان )0.83 میلیون تومان(

بنابراين:
قیمه کل نهايي سا ه ≈ ۲8٬0۰۰٬۰۰۰ تومان )بیسه و فه میلیون و دويسه زار تومان)


فصل دوا د : رندرگیری ا 44

## 12رندرگیری ا

شكل 1د12 جرتقیل )مجزا ا لیفتراک(

فصل دوا د : رندرگیری ا 45

شكل 2د12 لیفتراک و دکل متصل به آن

13پیوسه فصل سیزد : پیوسه 46


فصل سیزد : پیوسه 47


فصل سیزد : پیوسه 48

فصل سیزد : پیوسه 49

فصل سیزد : پیوسه 50


فصل سیزد : پیوسه 51


فصل سیزد : پیوسه 52

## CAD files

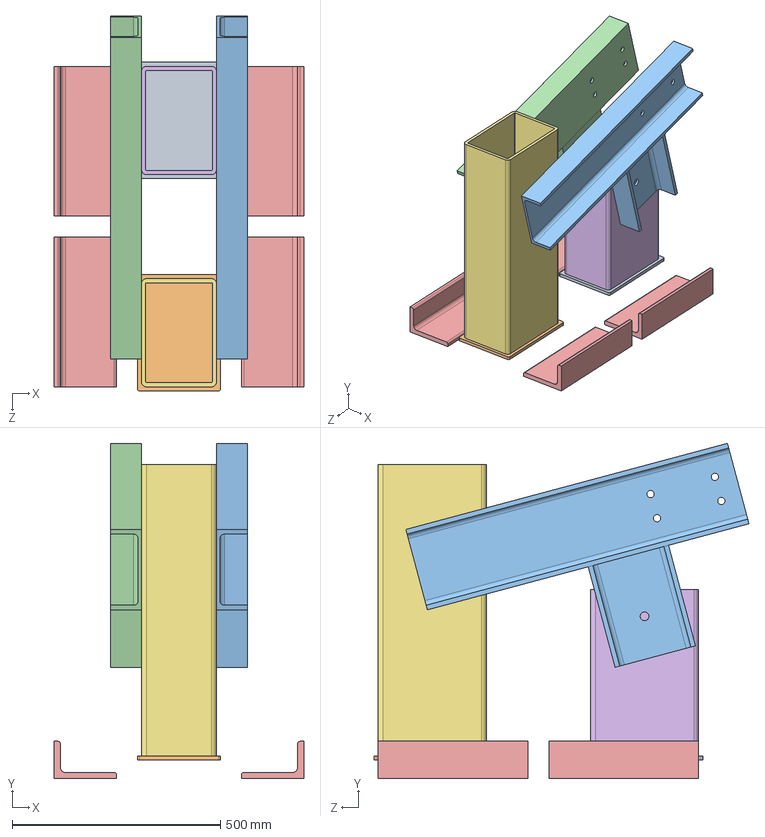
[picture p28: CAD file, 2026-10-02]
solidworks/Base2/BaseMent.SLDASM
600.0 x 805.7 x 901.0 mm
Behind_Stand
Front_Stand
L x 4
Connector
Connector_2
under_behind
under_Front

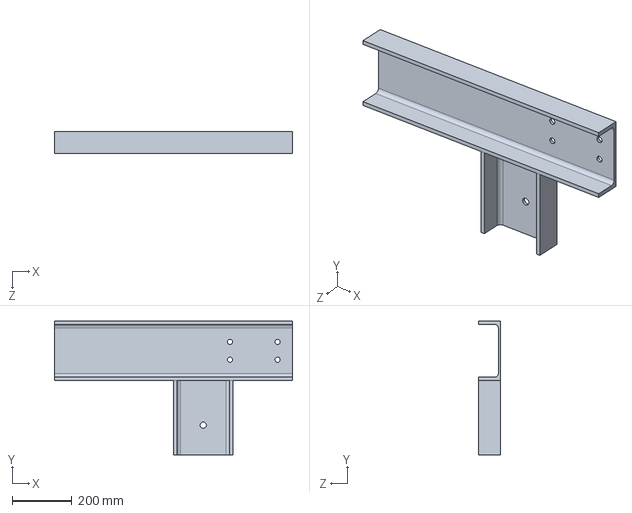
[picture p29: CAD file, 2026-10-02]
solidworks/Base2/Connector_2.SLDPRT
800.0 x 450.0 x 75.0 mm

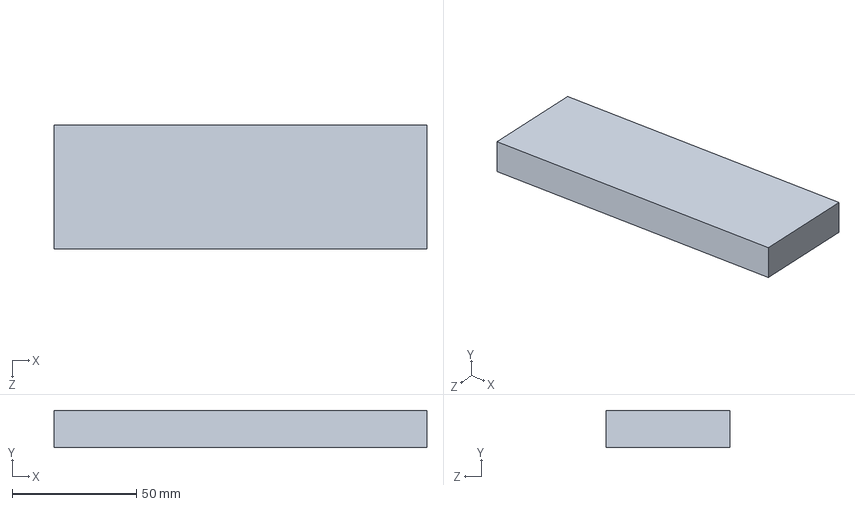
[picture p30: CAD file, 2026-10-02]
solidworks/Beam/Cover_Plane2.SLDPRT
150.0 x 15.0 x 50.0 mm

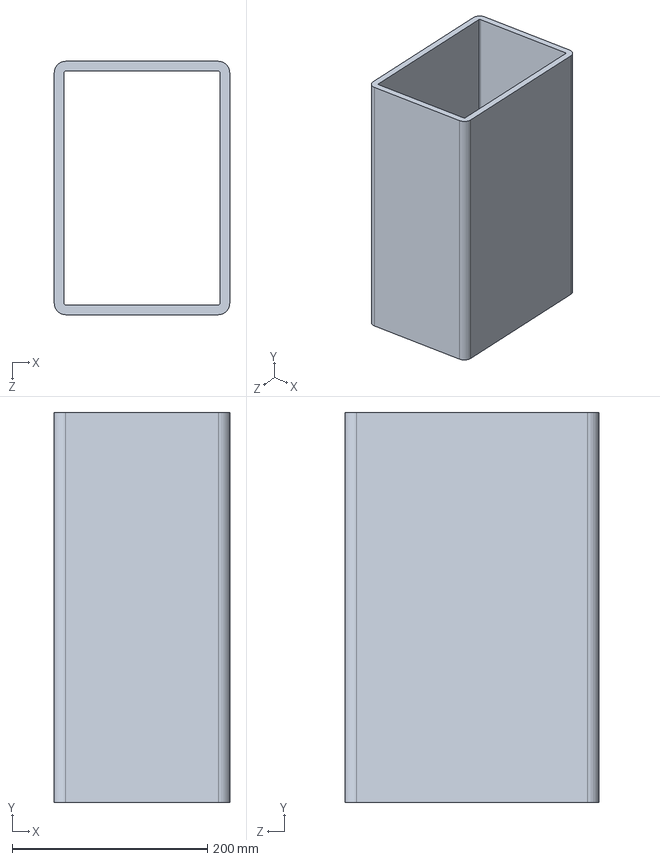
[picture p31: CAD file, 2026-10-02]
solidworks/Base2/Front_Stand.SLDPRT
180.0 x 400.0 x 260.0 mm

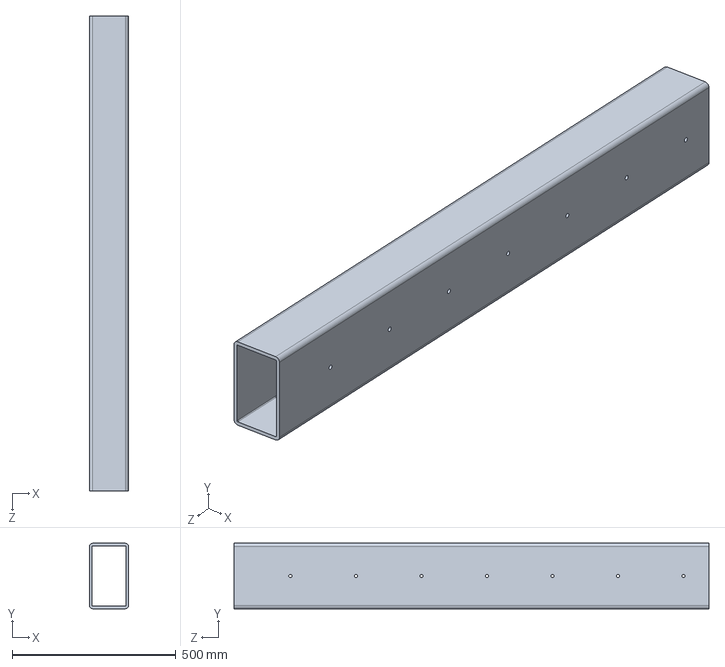
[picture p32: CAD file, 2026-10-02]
solidworks/Beam/Beam_2.SLDPRT
120.0 x 200.0 x 1450.0 mm

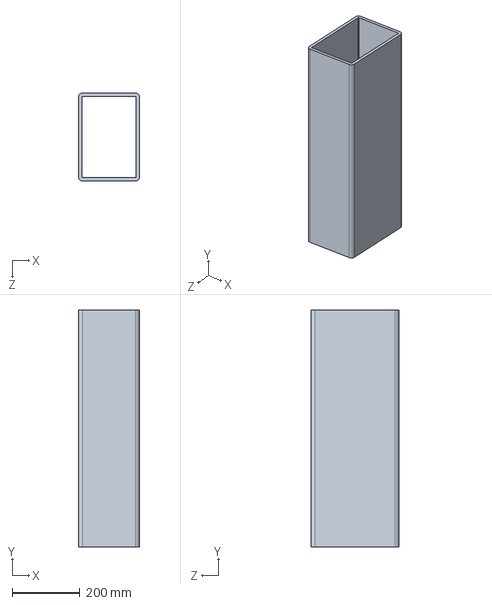
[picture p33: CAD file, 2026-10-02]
solidworks/Base2/Behind_Stand.SLDPRT
180.0 x 700.0 x 260.0 mm

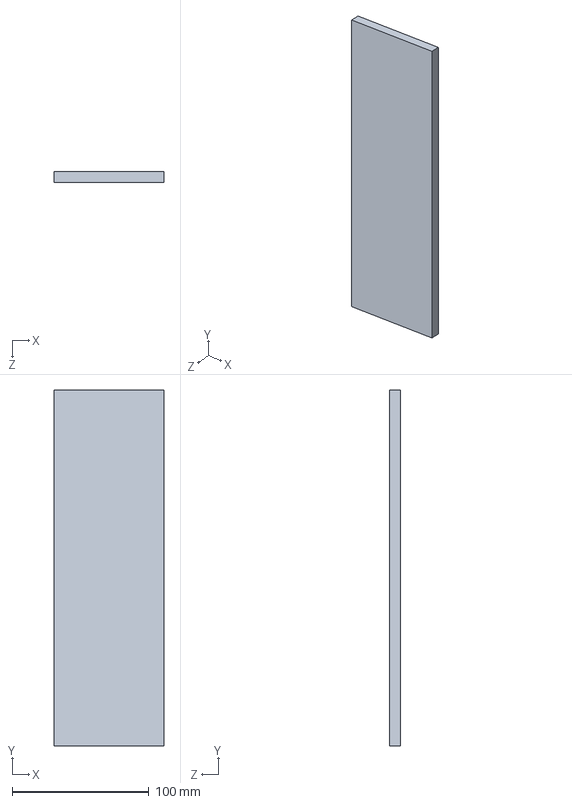
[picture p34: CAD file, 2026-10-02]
solidworks/Beam/Next_Varagh.SLDPRT
80.0 x 260.0 x 8.00 mm

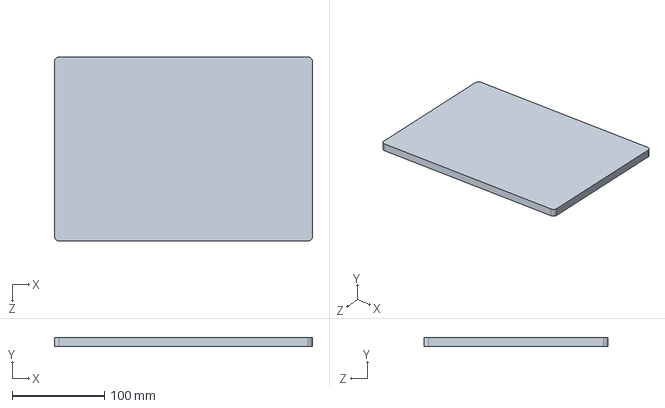
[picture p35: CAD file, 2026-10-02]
solidworks/Base2/under_behind.SLDPRT
280.0 x 10.0 x 200.0 mm

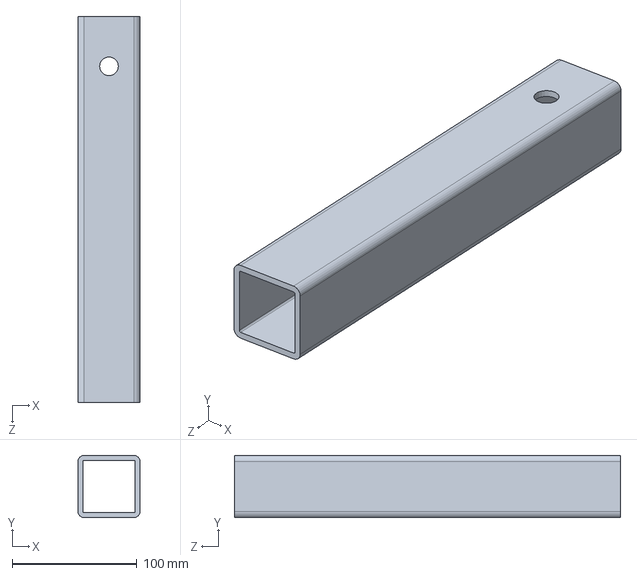
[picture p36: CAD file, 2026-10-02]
solidworks/Beam/Before_Gholab.SLDPRT
50.0 x 50.0 x 310.0 mm

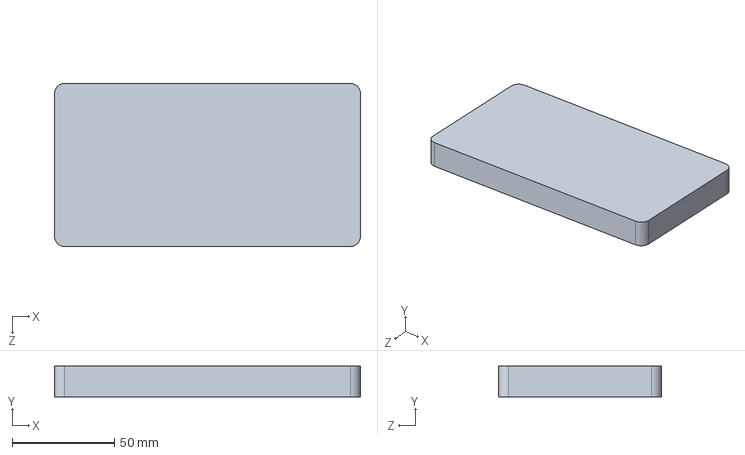
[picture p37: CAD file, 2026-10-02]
solidworks/Beam/Inner_plane.SLDPRT
150.0 x 15.0 x 80.0 mm

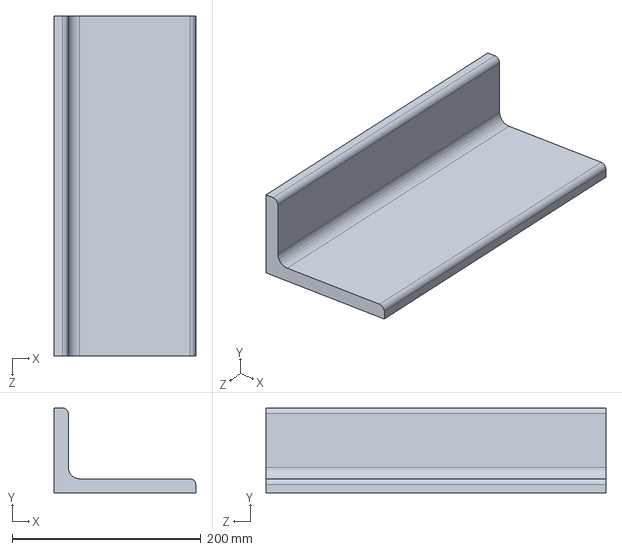
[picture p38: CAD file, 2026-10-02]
solidworks/Base2/L.SLDPRT
150.0 x 90.0 x 360.0 mm

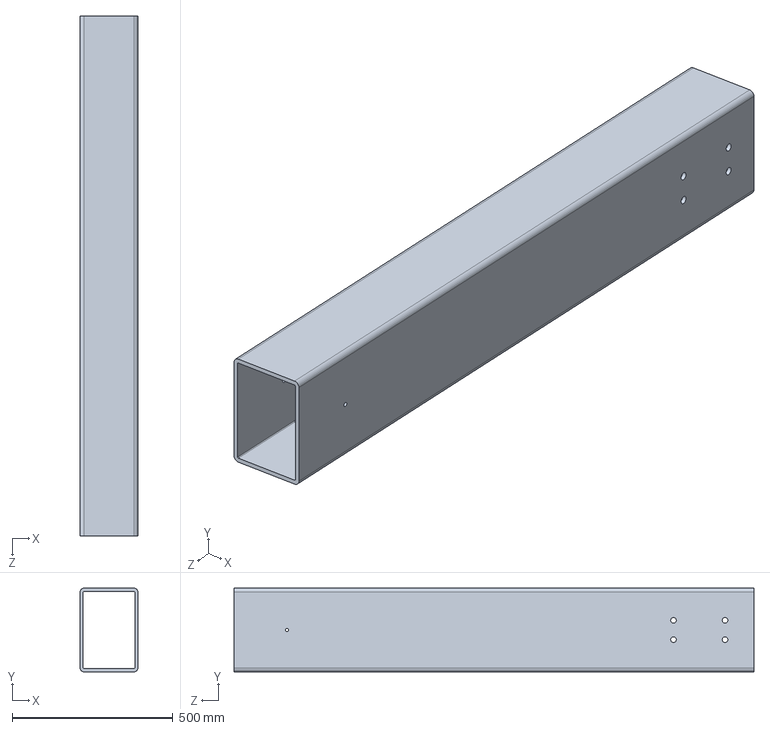
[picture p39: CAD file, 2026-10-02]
solidworks/Beam/Beam_Profile.SLDPRT
180.0 x 260.0 x 1615.0 mm

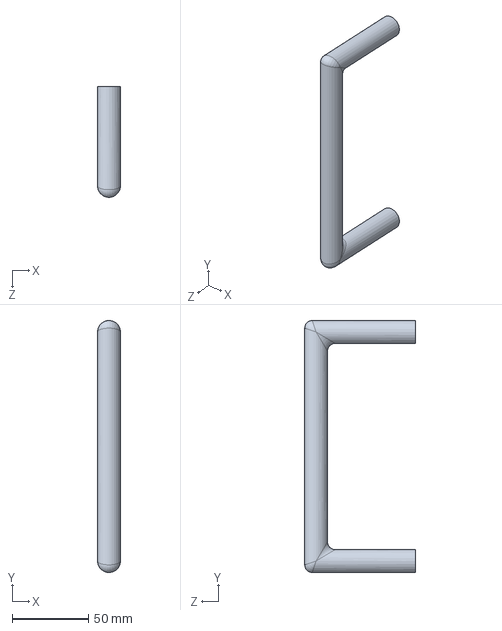
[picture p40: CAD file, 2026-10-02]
solidworks/Beam/Handle.SLDPRT
15.0 x 165.0 x 72.5 mm

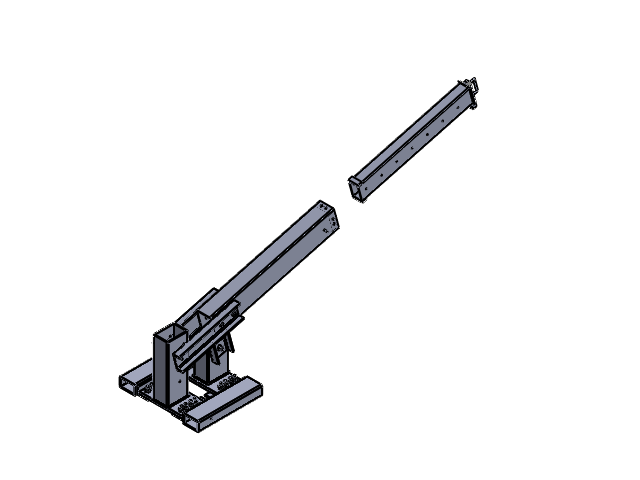
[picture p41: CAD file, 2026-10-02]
solidworks/Fork2.SLDASM
Behind_Stand
Front_Stand
L x 4
On_Shakhak x 2
Varagh x 2
Connector
Connector_2
under_behind
under_Front
Beam_2
Beam_Profile
Lower_Varagh
Inner_plane x 2
Inner_plane_3 x 2
Front_Varagh
Before_Gholab
Handle
inner_left_right x 2
formed hex screw_am x 33
flat washer narrow_am x 66
hex nut heavy_am x 25
hex flange nut_am x 8
hex flange screw_am x 10
Pin1
Pin2

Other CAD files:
solidworks/Built.SLDASM
solidworks/Beam/Beam_Base.SLDASM
solidworks/Base2/Connector.SLDPRT
solidworks/Base2/under_Front.SLDPRT
solidworks/Base2/On_Shakhak.SLDPRT
solidworks/Base2/Pin2.SLDPRT
solidworks/Base2/Varagh.SLDPRT
solidworks/BaseMent.SLDDRW
solidworks/BaseMent3.SLDDRW
solidworks/BaseMent_2.SLDDRW
solidworks/Beam/Cover_Plane1.SLDPRT
solidworks/Beam/Front_Varagh.SLDPRT
solidworks/Beam/Inner_plane_2.SLDPRT
solidworks/Beam/Inner_plane_3.SLDPRT
solidworks/Beam/Lower_Varagh.SLDPRT
solidworks/Beam/Pin1.SLDPRT
solidworks/Beam/Upper_Varagh.SLDPRT
solidworks/Beam/inner_left_right.SLDPRT
solidworks/Beam_Base.SLDDRW
solidworks/Beam_Base2.SLDDRW
solidworks/Drawings/BaseMent1.SLDDRW
solidworks/Drawings/BaseMent_2.SLDDRW
solidworks/Drawings/Beam_Base1.SLDDRW
solidworks/Drawings/Beam_Base2.SLDDRW
solidworks/Drawings/Katalog.SLDDRW
solidworks/Drawings/Mass_0.SLDDRW
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

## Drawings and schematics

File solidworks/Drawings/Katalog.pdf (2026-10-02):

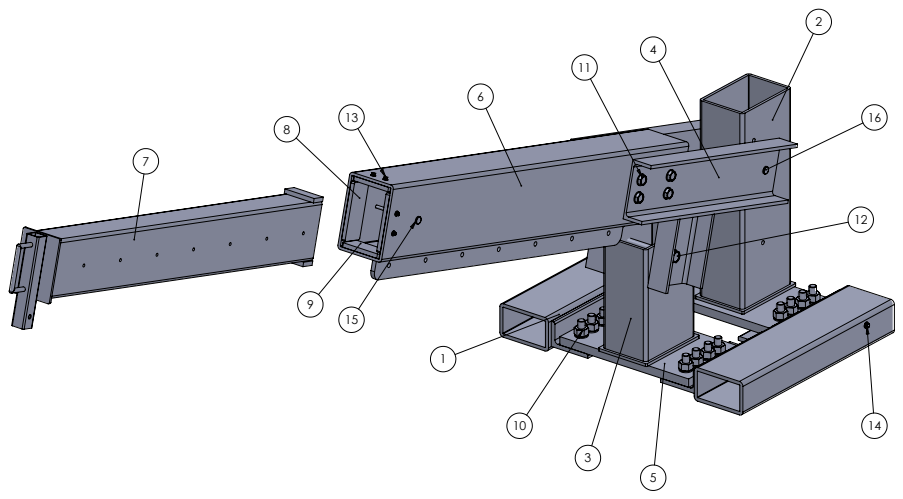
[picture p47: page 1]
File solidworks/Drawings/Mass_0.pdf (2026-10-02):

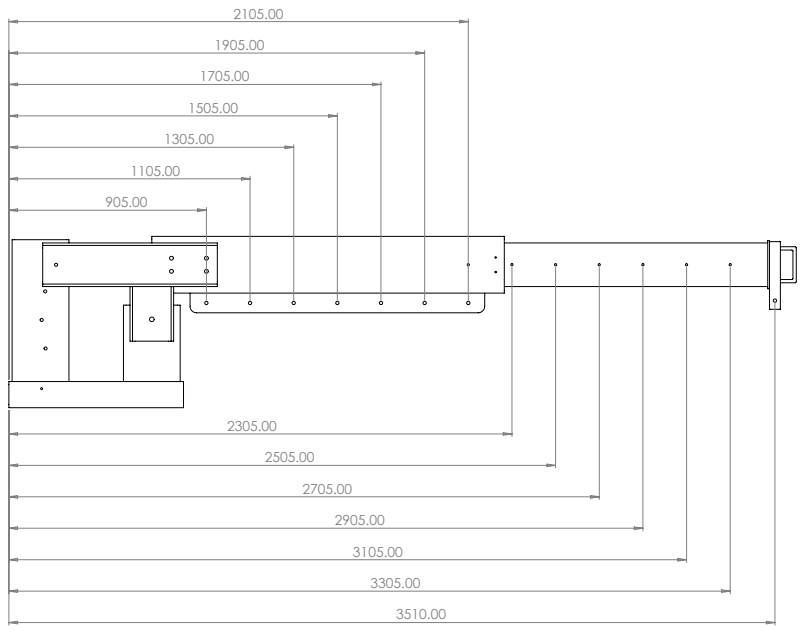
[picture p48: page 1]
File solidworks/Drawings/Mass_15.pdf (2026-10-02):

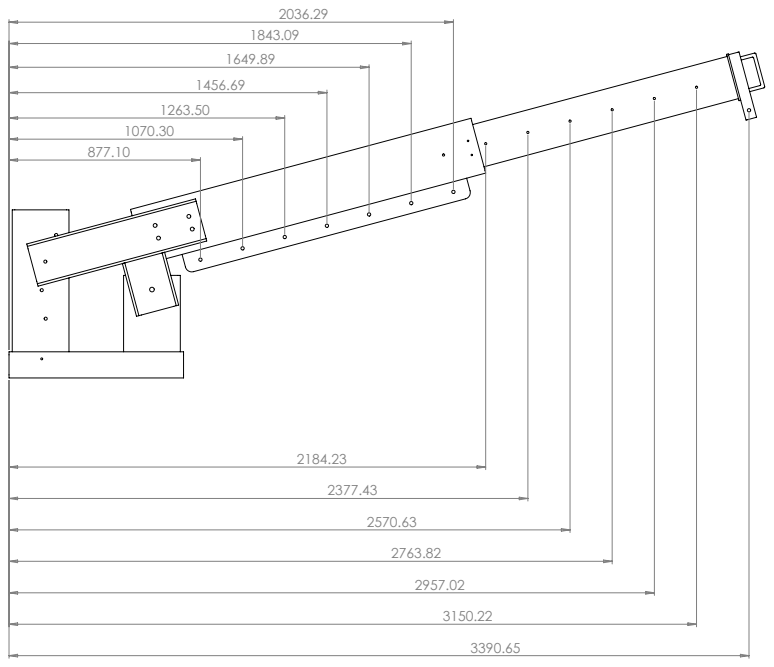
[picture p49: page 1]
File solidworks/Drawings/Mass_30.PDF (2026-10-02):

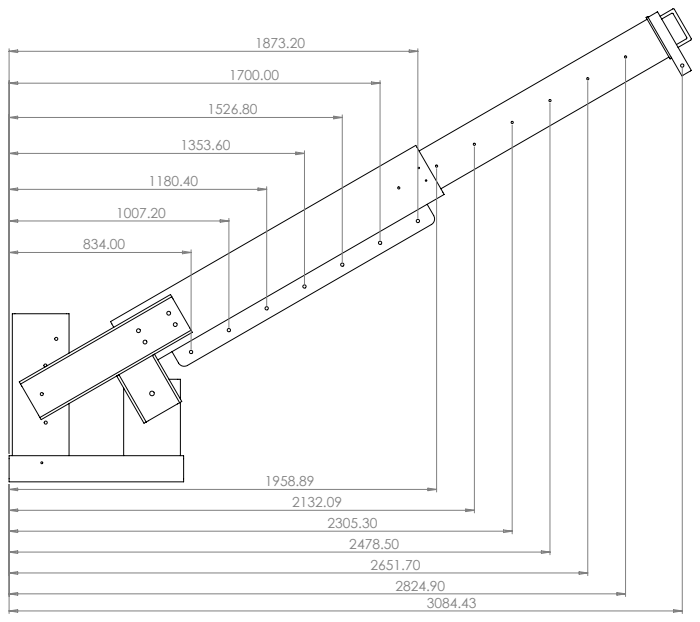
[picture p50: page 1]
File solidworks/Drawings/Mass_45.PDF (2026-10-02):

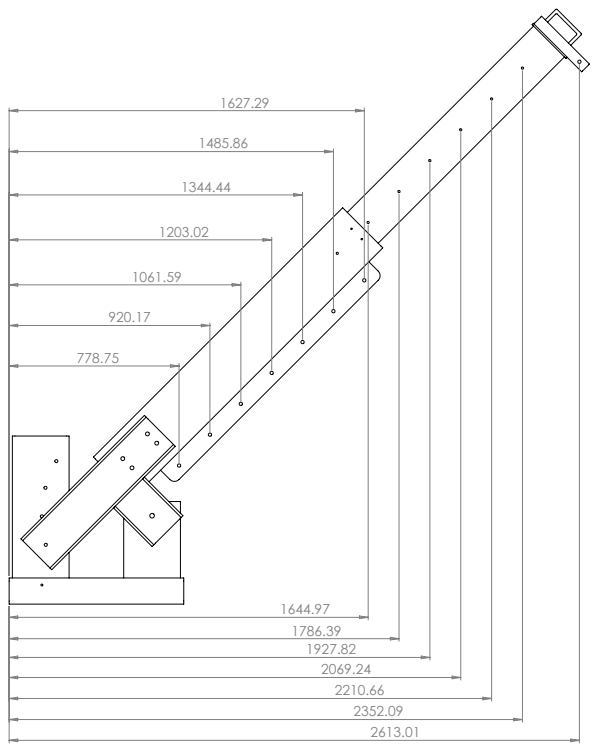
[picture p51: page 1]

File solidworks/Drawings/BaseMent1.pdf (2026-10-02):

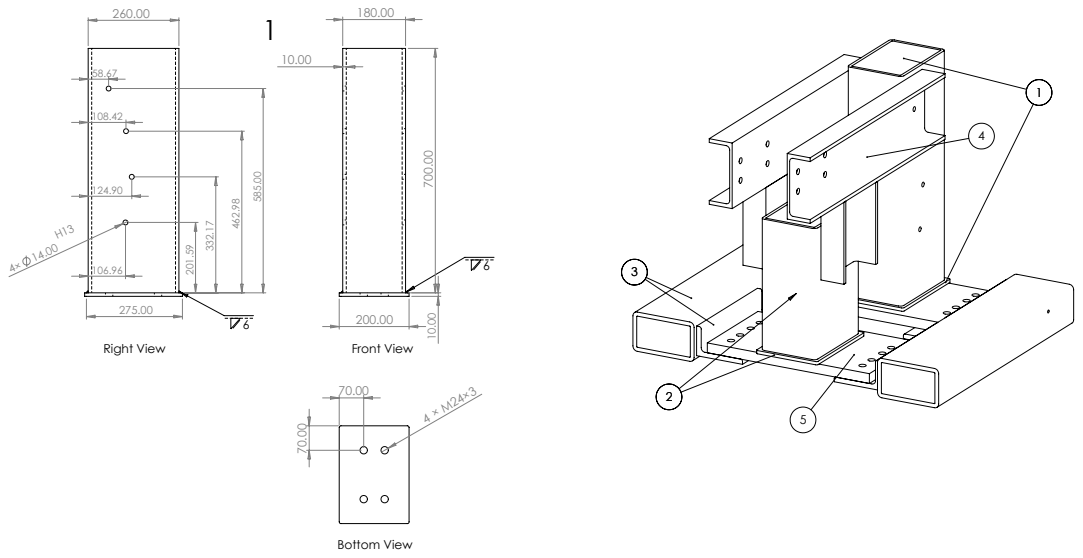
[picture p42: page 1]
Right View; Front View; Bottom View

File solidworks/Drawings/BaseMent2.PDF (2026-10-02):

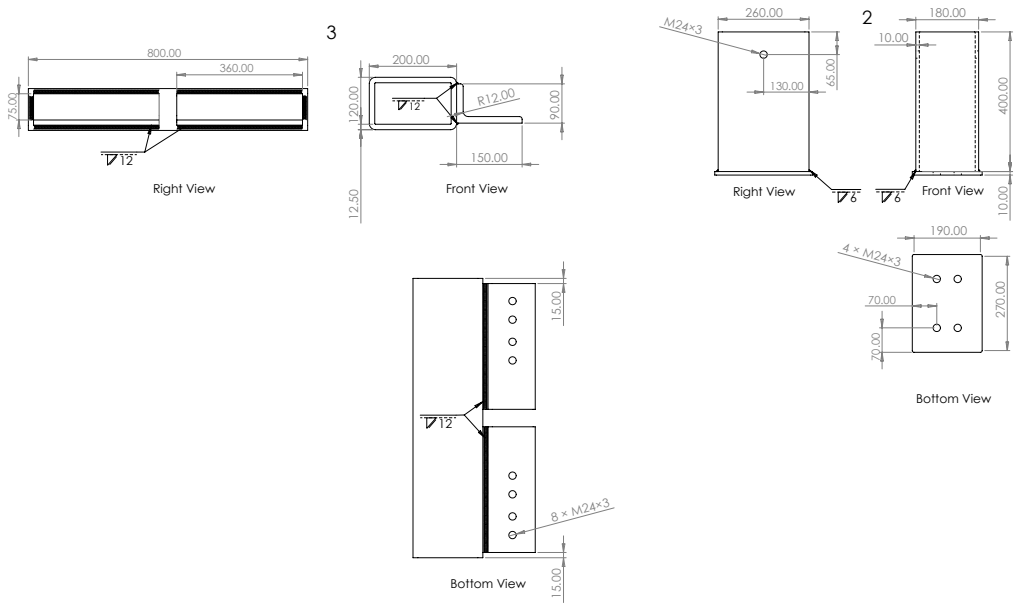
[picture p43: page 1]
Front View 6; Right View; Bottom View; Front View

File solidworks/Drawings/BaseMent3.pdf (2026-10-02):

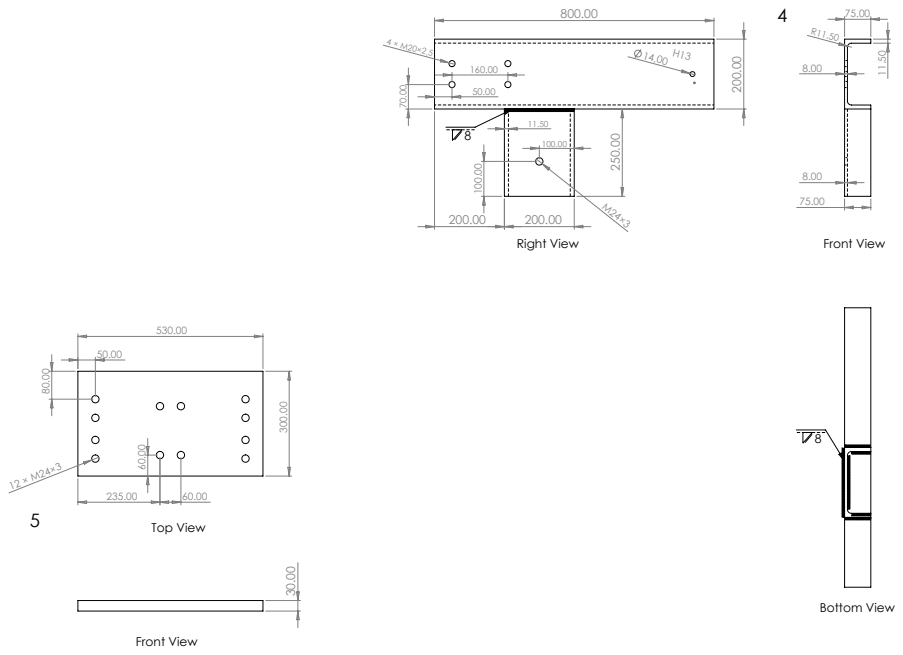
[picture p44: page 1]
Bottom View 8; Right View; Front View; Top View

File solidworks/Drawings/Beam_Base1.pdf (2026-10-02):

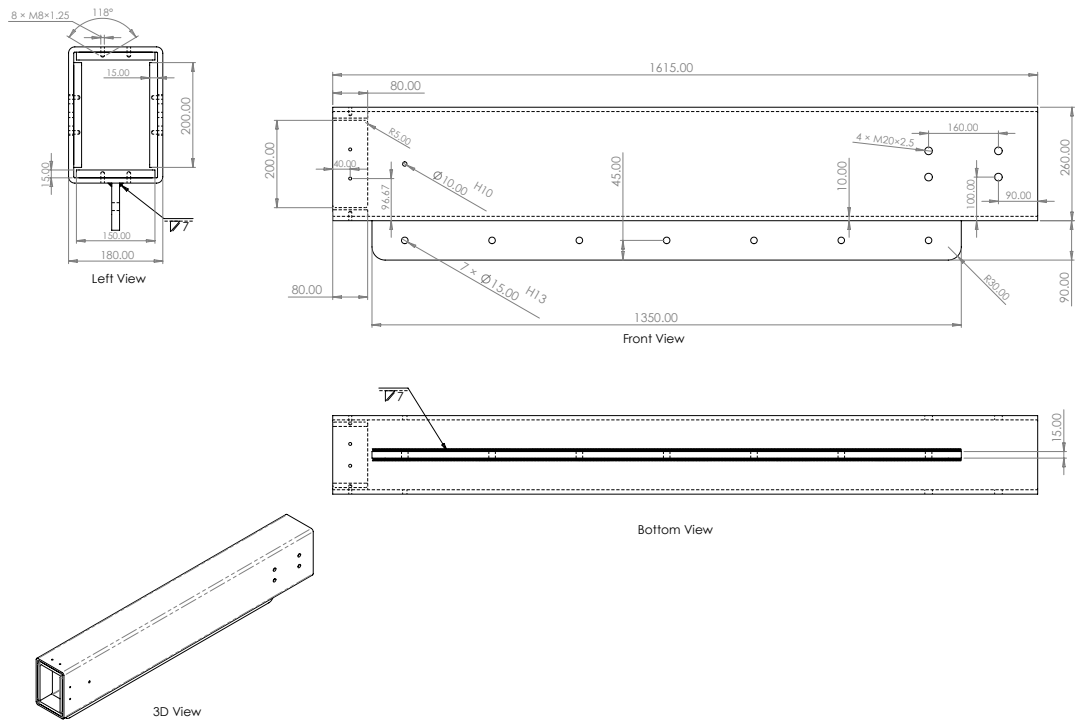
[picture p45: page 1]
Bottom View; 3D View; Left View; Front View

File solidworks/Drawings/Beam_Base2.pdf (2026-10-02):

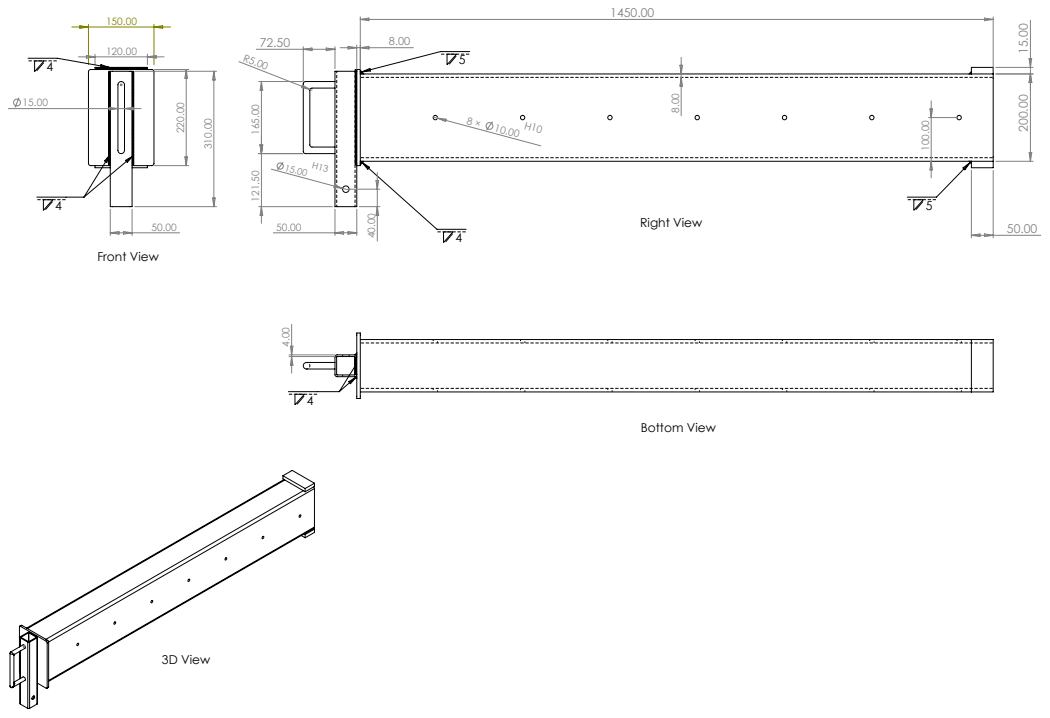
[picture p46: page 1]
Right View; Bottom View; 3D View; Front View
